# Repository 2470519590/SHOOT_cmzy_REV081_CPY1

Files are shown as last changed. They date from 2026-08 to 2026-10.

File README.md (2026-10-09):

# SHOOT_cmzy_REV081 枪管固件

## 项目职责

固件运行于 STM32F072C8x，负责双路红外 ADC 检测、射击计数与测速、热量和 LED 状态，以及 500 kbps 标准 CAN 通信。检测链路已经完全迁移到 DAC + ADC + DMA；运行时不再使用 VCNL4040、I2C 或旧 `shoot_detect` 检测器。

## ADC 采集与物理命名

- PA4/PA5：DAC 红外发射端，默认码值由 `ir_acquisition.h` 定义。
- PA1/ET1：物理后端，统一命名为 `barrel_rear`。
- PA3/ET2：物理前端，统一命名为 `barrel_front`。
- ADC DMA 原始顺序为 `[ET1, ET2, ...]`，50 μs 一个样本对，约 20 kHz/通道。
- `ir_acquisition` 只负责 DAC、ADC、DMA、定时和物理映射；`ir_detection` 只负责算法和诊断；`main` 负责业务副作用与调度。
- SWD 原始捕获保留 2000 帧结构：500 帧预触发、1500 帧后触发。

## 检测算法

启动和 `0x220` 重校准使用约 1 s 采样窗口，并以稳健中值建立两路基线。运行时先比较样本与阈值，再按约 `1/2048` 慢速更新基线。

```text
front_threshold = front_baseline + 60 ADC
rear_threshold  = rear_baseline + 18 ADC
front/rear 最大脉宽 = 6 ms
rear 最小脉宽 = 0.3 ms
速度范围 = 2~15 m/s
传感器间距 = 50 mm
```

物理顺序为后端先、前端后。前端每个有效脉冲始终产生一个且仅一个射击事件；后端只作为可选测速候选。测速使用峰值时间差：

```text
peak_delta_us = front_peak_us - rear_peak_us
3.333 ms <= peak_delta_us <= 25 ms
speed = 50 mm / peak_delta
```

后端候选使用 8 项队列，前端事件选择时间窗内最近的、尚未消费的后端峰值。没有有效匹配时速度无效，但前端射击计数不受影响。`barrel_mask` 固定为 `0`。

主要 Ozone 变量包括：`barrel_front_adc_raw`、`barrel_rear_adc_raw`、两路 baseline/trigger level、事件数和采样号、峰值 ADC/采样号、`ir_shot_count`、`ir_last_speed_mps`、`ir_last_speed_valid`、`ir_last_peak_delta_us`、`ir_pair_timeout_count`、`ir_unpaired_front_count` 和 `ir_unpaired_rear_count`。

## 应用链路

`main` 从检测层取出事件后执行一次本地计数关联、每发热量 `+10`（上限 200）和顶部 LED 效果，然后将同一个事件交给 CAN 发送队列。CAN 发送失败只保留队列事件重试，不重复执行本地热量和灯效。

- `0x230`：累计次数、速度（`uint16 = round(m/s × 10)`（分辨率 0.1 m/s），无效为 `0xFFFF`）、固定 `barrel_mask=0`、本发后热量。
- `0x232`：累计次数、最近速度（无效为 `0xFFFF`）、固定 `barrel_mask=0`、当前热量。
- `0x220`：主循环启动约 1 s ADC 重校准，校准期间不生成事件。
- `0x221`：前/后端校准前后 baseline，各一个小端 `uint16`。

完整字段和接收约束见 [docs/CAN_PROTOCOL.md](docs/CAN_PROTOCOL.md)。

## 目录

| 路径 | 用途 |
|---|---|
| `Core/Src/ir_acquisition.c` | DAC、ADC、DMA、采样定时和物理通道映射 |
| `Core/Src/ir_detection.c` | 基线、阈值、脉冲、峰值、候选匹配、事件和校准 |
| `Core/Src/main.c` | 初始化、事件消费、热量、LED、CAN 重试和任务调度 |
| `Core/Src/can_protocol.c` | CAN 编码、发送和接收协议 |
| `Core/Src/thermal.c` | 热量累加与冷却 |
| `Core/Src/led_rgb.c` | 顶部灯、队伍色、热量条和故障显示 |
| `Core/Src/reliability.c` | 弱故障及复位记录 |
| `tool/simulate_ir_detection.py` | ADC CSV 逐点回放参考实现 |
| `docs/adc_detection_tuning.md` | ADC 检测参数与诊断说明 |

## 构建与验证

使用现有 VS Code task `STM32: Build`，等价于：

```text
E:\GnuWin32\bin\make.exe -j2 all
```

软件验证包括 Python 数据回放、旧路径静态搜索、`git diff --check`、固件构建以及 ELF 的 SRAM/Flash 使用检查。未执行刷机；实板 Ozone 观察、CAN 总线和机械过管验证仍需在硬件环境完成。

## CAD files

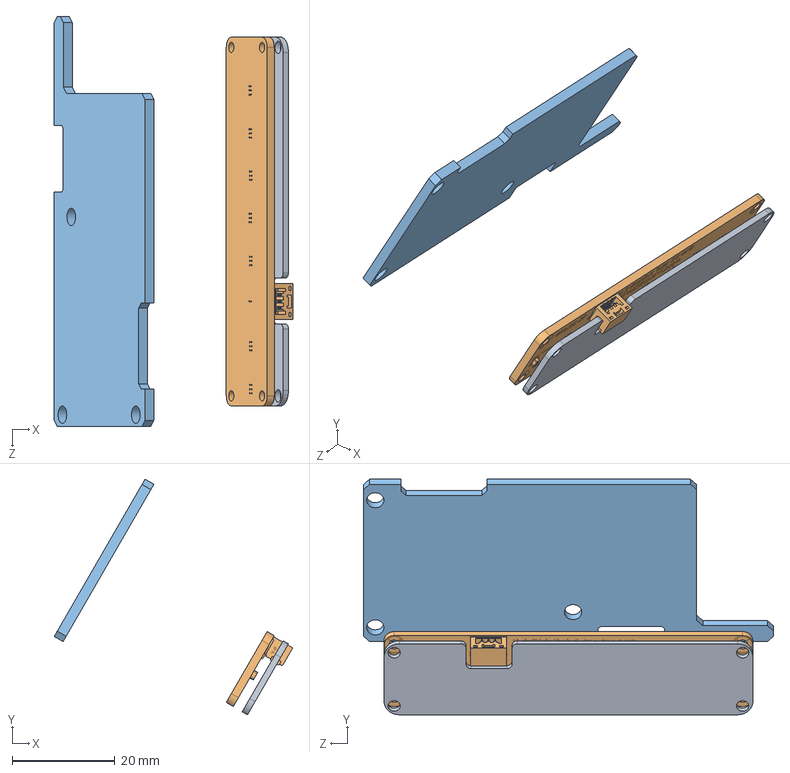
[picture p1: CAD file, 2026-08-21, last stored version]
3Ds/枪管081.SLDASM
46.5 x 46.0 x 80.0 mm
枪管驱动盖
3D_RGB_SHOOT_PCB1_2026-06-19.step
均光板_PCB

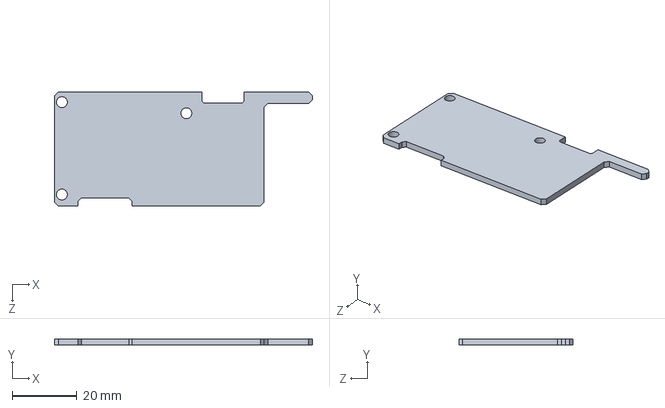
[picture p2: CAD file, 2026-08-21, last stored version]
3Ds/枪管驱动盖.SLDPRT
80.0 x 2.00 x 35.5 mm

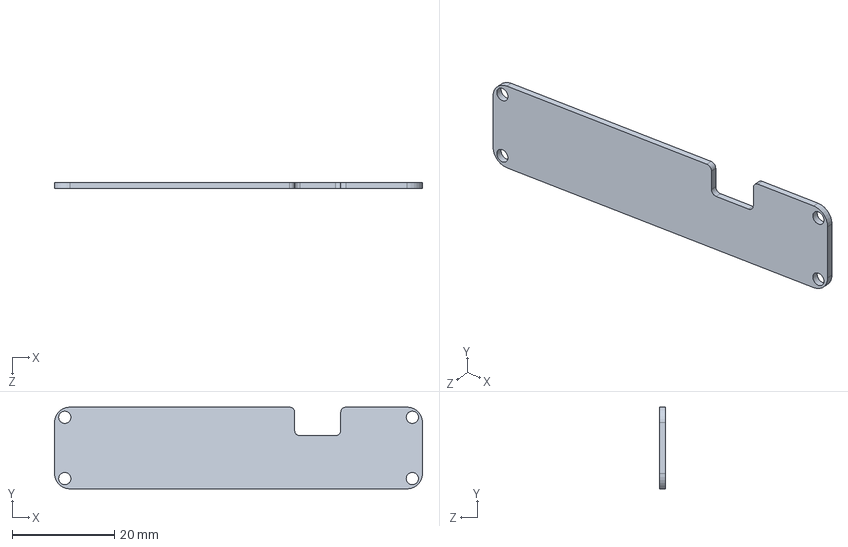
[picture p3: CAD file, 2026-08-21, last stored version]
3Ds/均光板_PCB.SLDPRT
72.0 x 16.0 x 1.20 mm

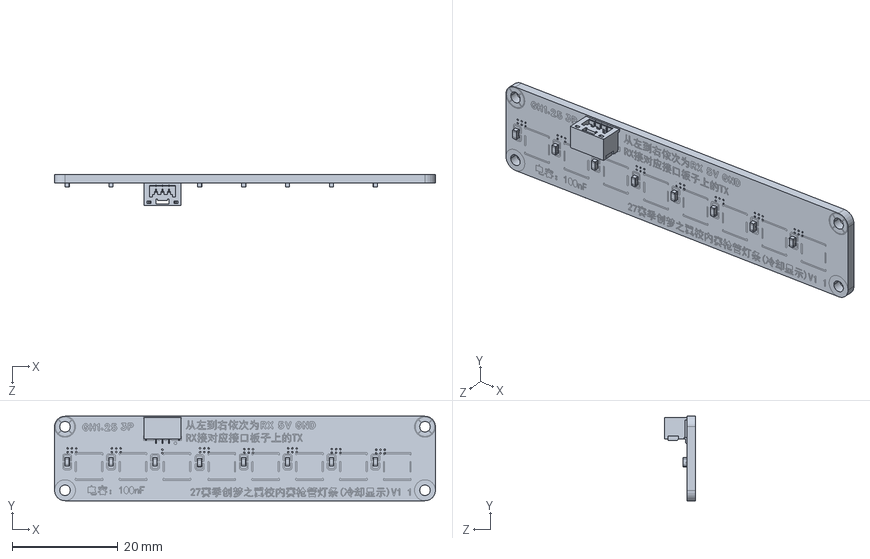
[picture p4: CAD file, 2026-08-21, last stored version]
3Ds/3D_RGB_SHOOT_PCB1_2026-06-19.step.SLDPRT
72.0 x 16.0 x 5.92 mm

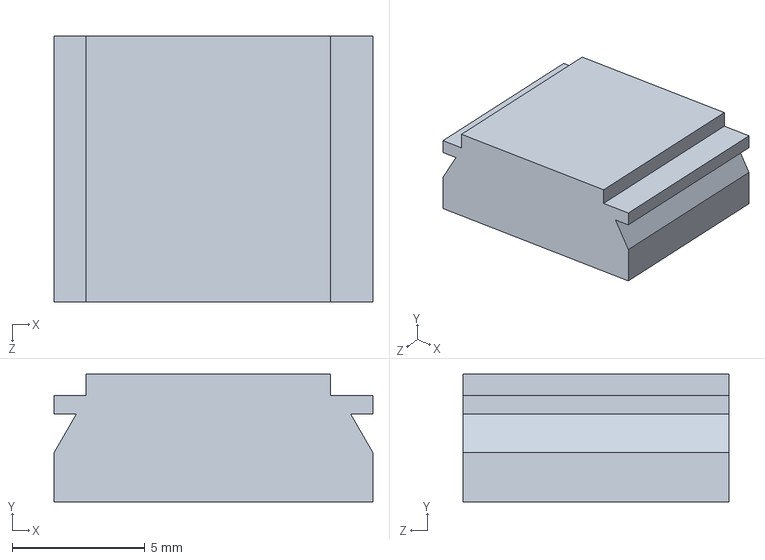
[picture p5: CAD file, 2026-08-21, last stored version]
3Ds/均光板盖.SLDPRT
12.0 x 4.80 x 10.0 mm

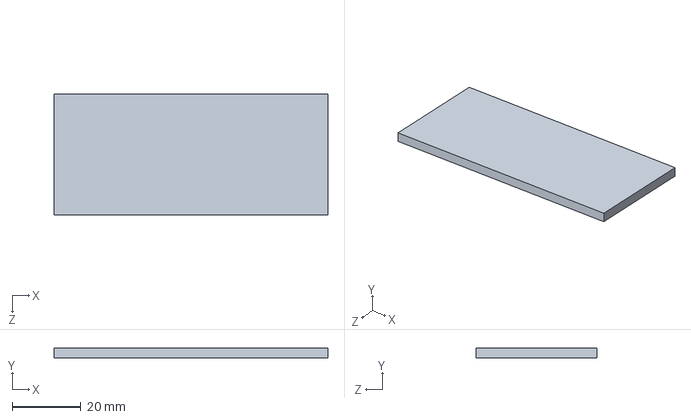
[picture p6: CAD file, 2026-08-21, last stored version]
3Ds/备份 属于 枪管驱动盖.SLDPRT
80.0 x 3.00 x 35.5 mm

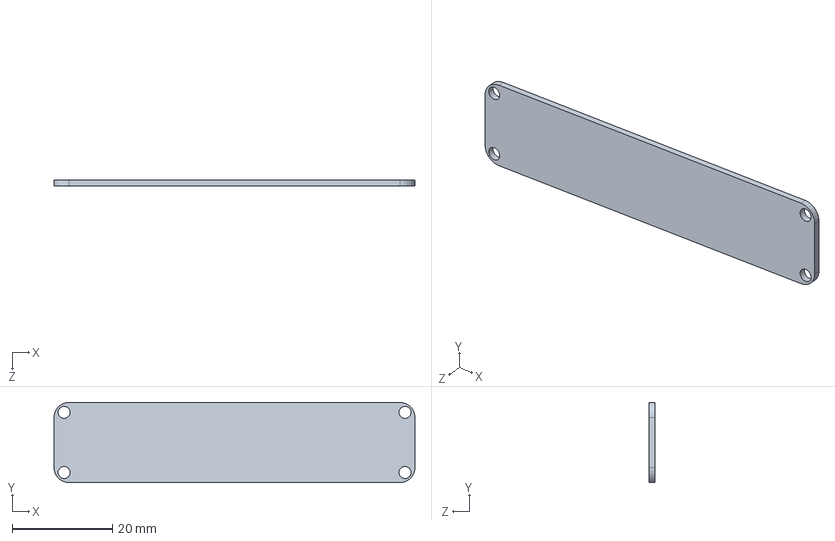
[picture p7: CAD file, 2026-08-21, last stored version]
3Ds/备份 属于 均光板_PCB.SLDPRT
72.0 x 16.0 x 1.20 mm

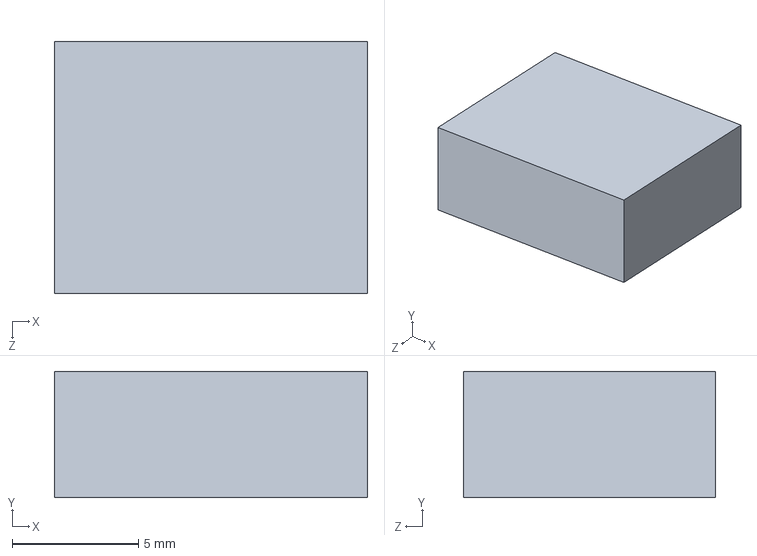
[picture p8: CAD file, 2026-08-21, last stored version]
3Ds/备份 属于 均光板盖.SLDPRT
12.4 x 5.00 x 10.0 mm

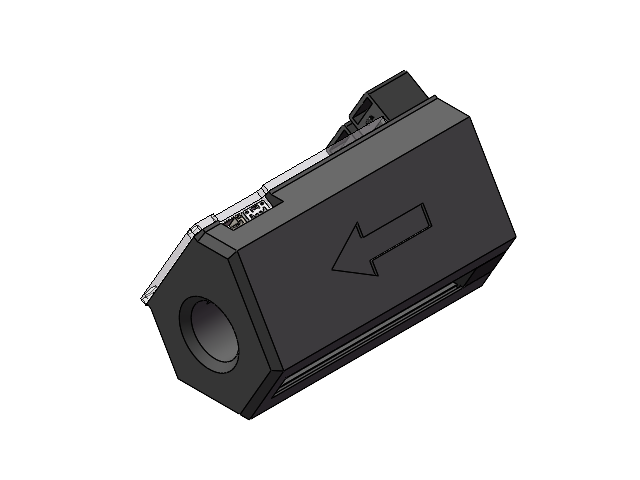
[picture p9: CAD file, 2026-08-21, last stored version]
3Ds/枪管08.SLDASM
枪管08
3D_EVE_0.8.1_2026-06-16.step
枪管驱动盖
均光板盖

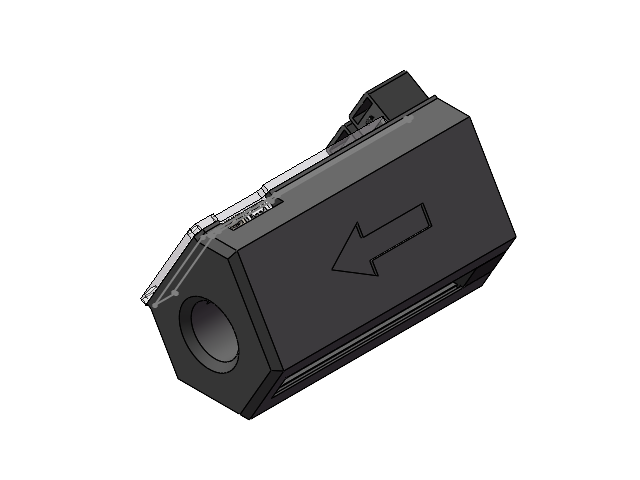
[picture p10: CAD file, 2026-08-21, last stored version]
3Ds/备份 属于 枪管08.SLDASM
枪管08
3D_EVE_0.8.1_2026-06-16.step
枪管驱动盖
均光板盖

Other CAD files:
3Ds/备份 属于 枪管081.SLDASM
3Ds/备份 属于 3D_RGB_SHOOT_PCB1_2026-06-19.step.SLDPRT
3Ds/3D_RGB_SHOOT_PCB1_2026-06-19.step
3Ds/备份 属于 枪管08.SLDPRT
3Ds/备份 属于 枪管081.SLDPRT
3Ds/枪管08.SLDPRT
3Ds/枪管081.SLDPRT

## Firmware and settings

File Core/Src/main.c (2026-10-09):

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
/* Includes ------------------------------------------------------------------*/
#include "main.h"

/* USER CODE BEGIN Includes */
#include "ir_acquisition.h"
#include "ir_detection.h"
#include "can_protocol.h"
#include "led_rgb.h"
#include "ws2812_uart.h"
#include "reliability.h"
#include "thermal.h"
/* USER CODE END Includes */

CAN_HandleTypeDef hcan;

DAC_HandleTypeDef hdac;
ADC_HandleTypeDef hadc;
DMA_HandleTypeDef hdma_adc;

TIM_HandleTypeDef htim3;

TIM_HandleTypeDef htim14;
TIM_HandleTypeDef htim15;
TIM_HandleTypeDef htim16;

UART_HandleTypeDef huart1;
UART_HandleTypeDef huart3;
DMA_HandleTypeDef hdma_usart3_tx;
IWDG_HandleTypeDef hiwdg;

/* USER CODE BEGIN PV */
ShootData_Report_t g_shoot_report;
CAN_ErrorStats_t g_can_stats = {0};

/* 10 Hz status-report tick (set by TIM14 ISR, cleared by main loop) */
volatile bool g_sensor_tick_10hz = false;

/* 10 Hz LED refresh tick (set by TIM15 ISR, cleared by main loop) */
volatile bool g_led_tick_10hz = false;

/* Firmware identity and shot-to-LED trace points.
   This value is deliberately changed with this diagnostic build.  It lets the
   debugger prove which image is executing; it is not derived from the source
   timestamp. */
#if SHOOT_CAN_DIAGNOSTIC_SILENT
#define FW_BUILD_MAGIC  0x26091002UL /* CAN silent diagnostic image */
#elif SHOOT_CAN_DIAGNOSTIC_NO_APP_TX
#define FW_BUILD_MAGIC  0x26091004UL /* RX-only + reset-cause diagnostic */
#else
#define FW_BUILD_MAGIC  0x26083001UL /* normal operational image */
#endif
volatile uint32_t g_dbg_firmware_build_magic = FW_BUILD_MAGIC;
/* A mailbox accept is not yet a physical CAN ACK; it only means bxCAN took
   the 0x230 request.  Keep the two counters separate from sensor counters. */
volatile uint32_t g_dbg_shot_mailbox_accept_count = 0;
volatile uint32_t g_dbg_shot_led_start_count = 0;
volatile uint32_t g_dbg_last_shot_led_event_count = 0;

/* Keep CAN fault evidence as scalar volatile symbols.  Some GDB frontends
 * cannot create a watch for a member of CAN_ErrorStats_t, especially after
 * -Og optimisation.  These are deliberately boring debugger entry points. */
volatile uint32_t g_dbg_can_esr = 0U;
volatile uint32_t g_dbg_can_btr = 0U;
volatile uint8_t  g_dbg_can_lec = 0U;
volatile uint8_t  g_dbg_can_tec = 0U;
volatile uint8_t  g_dbg_can_rec = 0U;
volatile uint8_t  g_dbg_can_bus_off = 0U;

/* Debug LED override — write from debugger:
   g_led_cmd = 1 → 9 LEDs all green  (WS2812_COLOR(255,0,0))
            = 2 → 9 LEDs all red    (WS2812_COLOR(0,255,0))
            = 3 → 9 LEDs all blue   (WS2812_COLOR(0,0,255))
            = 4 → team color (current team)
            = 5 → all off
            = 0 → normal operation (自动)
   Set g_led_cmd_count to limit lit LEDs (0 = all 9). */
volatile uint8_t  g_led_cmd        = 0;
volatile uint8_t  g_led_cmd_count  = 0;
volatile uint8_t  g_heat_debug     = 0;   /* current local heat, 0–200           */
/* ADC detection owns calibration readiness after its startup window. */
static bool g_boot_report_pending = true;
static uint8_t g_pending_strong_fault;
/* USER CODE END PV */



void SystemClock_Config(void);
static void MX_GPIO_Init(void);
static void MX_DMA_Init(void);
static void MX_CAN_Init(void);
static void MX_USART1_UART_Init(void);
static void MX_DAC_Init(void);
static void MX_USART3_UART_Init(void);
static void MX_TIM14_Init(void);
static void MX_TIM15_Init(void);
static void MX_TIM16_Init(void);
static void MX_IWDG_Init(void);
/**
  * @brief  The application entry point.
  * @retval int
  */
int main(void)
{

  /* MCU Configuration--------------------------------------------------------*/

  /* Reset of all peripherals, Initializes the Flash interface and the Systick. */
  HAL_Init();

  /* Read the reset cause and any retained HardFault/CAN Bus-Off note. */
  Reliability_EarlyInit();

  /* Configure the system clock */
  SystemClock_Config();

  /* Initialize all configured peripherals */
  MX_GPIO_Init();
  MX_DMA_Init();
  MX_CAN_Init();
  MX_DAC_Init();
  MX_USART1_UART_Init();
  MX_USART3_UART_Init();
  MX_TIM14_Init();
  MX_TIM15_Init();
  MX_TIM16_Init();
  /* USER CODE BEGIN 2 */

  /* ---- NVIC configuration ---- */
  Thermal_Init(HAL_GetTick());
  HAL_NVIC_DisableIRQ(EXTI4_15_IRQn);
  HAL_NVIC_SetPriority(TIM14_IRQn, 3, 0);      /* TIM14: 10 Hz sensor tick   */
  HAL_NVIC_EnableIRQ(TIM14_IRQn);
  HAL_NVIC_SetPriority(TIM15_IRQn, 3, 0);      /* TIM15: 10 Hz LED tick       */
  HAL_NVIC_EnableIRQ(TIM15_IRQn);
  HAL_NVIC_SetPriority(CEC_CAN_IRQn, 2, 0);    /* CAN: referee comms         */
  HAL_NVIC_EnableIRQ(CEC_CAN_IRQn);

  /* Start TIM16 free-running counter (PSC/ARR set by MX_TIM16_Init) */
  __HAL_TIM_ENABLE(&htim16);

  /* ---- Start fixed-code DAC emitters and timer-triggered raw acquisition ---- */
  IR_Detection_Init();
  IR_Acquisition_RegisterSampleHandler(IR_Detection_OnPhysicalSample);
  if (IR_Acquisition_Init() != HAL_OK) {
      Error_Handler();
  }
  /* The ADC detector owns the application shot path. */
  Reliability_SetWeakFault(REL_WEAK_SHOOT_DETECT, true);

  /* ---- Init board status LED (RGB_TX3) and eight-pixel strip (RGB_TX2) ---- */
  LedStrip_Init();
  LedStrip_SetTeam(TEAM_BLUE);
  LedStrip_StartBootEffect(HAL_GetTick());

  /* ---- Init CAN protocol (slave-only) ---- */
  CANProtocol_Init(&hcan);
  /* Only receive the gun command range (0x220..0x23F), standard data frames.
     Armor-board traffic never reaches this CAN RX ISR. */
  CAN_FilterTypeDef can_filter = {0};
  can_filter.FilterBank = 0;
  can_filter.FilterMode = CAN_FILTERMODE_IDMASK;
  can_filter.FilterScale = CAN_FILTERSCALE_32BIT;
  can_filter.FilterIdHigh = 0x4400; /* 0x220 << 5 */
  can_filter.FilterIdLow = 0x0000;
  can_filter.FilterMaskIdHigh = 0xFC00; /* match 0x220..0x23F */
  can_filter.FilterMaskIdLow = 0x0006;  /* IDE=0, RTR=0 */
  can_filter.FilterFIFOAssignment = CAN_FILTER_FIFO0;
  can_filter.FilterActivation = ENABLE;
  can_filter.SlaveStartFilterBank = 0;
  if (HAL_CAN_ConfigFilter(&hcan, &can_filter) != HAL_OK) {
      Error_Handler();
  }
  /* Start CAN and enable receive interrupt.  The silent diagnostic image
     deliberately remains fully powered and receives 0x220..0x23F, but bxCAN
     neither ACKs nor drives any CAN bit.  It is only for isolating a
     gun-side CAN fault; production builds always use normal mode. */
  if (HAL_CAN_Start(&hcan) != HAL_OK) {
      Error_Handler();
  }
  if (HAL_CAN_ActivateNotification(&hcan,
        CAN_IT_RX_FIFO0_MSG_PENDING) != HAL_OK) {
      Error_Handler();
  }
  g_can_stats.state = (uint8_t)HAL_CAN_GetState(&hcan);

  MX_IWDG_Init();

  /* Report a prior strong reset before announcing this successful startup. */
  g_pending_strong_fault = Reliability_GetPendingStrongMask();
  /* Keep the debugger-visible image identity linked into the final ELF. */
  if (g_dbg_firmware_build_magic != FW_BUILD_MAGIC) {
      Error_Handler();
  }
  /* USER CODE END 2 */

  /* Infinite loop */
  /* USER CODE BEGIN WHILE */
  while (1)
  {
    /* USER CODE END WHILE */

    /* USER CODE BEGIN 3 */
    if (CANProtocol_TakeCalibrationRequest()) {
        (void)IR_Detection_RequestCalibration();
    }

    IR_Acquisition_PublishLatest();
    IR_Acquisition_ServiceRawCapture();
    if (g_pending_strong_fault != 0U &&
        CANProtocol_SendStrongFault(g_pending_strong_fault) == HAL_OK) {
        g_pending_strong_fault = 0U;
    }
    if (g_boot_report_pending && g_pending_strong_fault == 0U &&
        IR_Detection_IsCalibrationReady() &&
        CANProtocol_SendBoot() == HAL_OK) {
        g_boot_report_pending = false;
    }

    static uint16_t old_front, new_front, old_rear, new_rear;
    static bool calibration_ack_pending;
    if (!calibration_ack_pending &&
        IR_Detection_TakeCalibrationResult(&old_front, &new_front,
                                           &old_rear, &new_rear)) {
        calibration_ack_pending = true;
    }
    if (calibration_ack_pending &&
        CANProtocol_SendCalibrationAck(old_front, new_front,
                                       old_rear, new_rear) == HAL_OK) {
        calibration_ack_pending = false;
    }

    uint32_t now_tick = HAL_GetTick();
    Thermal_Update(now_tick);
    g_heat_debug = Thermal_GetHeat();
    LedStrip_SetOverheatAlert(
        Thermal_IsOverheatIndicatorActive(now_tick));

    /* Drain acquisition events regardless of CAN availability. */
    static ShootEvent_t can_shots[IR_SHOT_EVENT_CAPACITY];
    static uint8_t can_shot_head, can_shot_count;
    static uint32_t can_shot_dropped;
    static uint32_t locally_accounted_shots;
    ShootEvent_t shot_event;
    while (IR_Detection_PeekShotEvent(&shot_event)) {
        IR_Detection_DropShotEvent();
        /* Count gaps represent detection queue loss, not lost physical shots. */
        while ((int32_t)(shot_event.shot_count - locally_accounted_shots) > 0) {
            locally_accounted_shots++;
            g_heat_debug = Thermal_AddShot(now_tick);
            g_dbg_shot_led_start_count++;
            g_dbg_last_shot_led_event_count = locally_accounted_shots;
            LedStrip_StartShotEffect(now_tick);
        }
        shot_event.heat_level = g_heat_debug;
        if (can_shot_count < IR_SHOT_EVENT_CAPACITY) {
            uint8_t tail = (uint8_t)((can_shot_head + can_shot_count) % IR_SHOT_EVENT_CAPACITY);
            can_shots[tail] = shot_event;
            can_shot_count++;
        } else {
            can_shot_dropped++;
        }
    }
    /* Preserve local behavior even when the detection event queue overflowed. */
    uint32_t shot_primask = __get_PRIMASK();
    __disable_irq();
    uint32_t detected_shots = IR_Detection_PeekShotEvent(&shot_event)
        ? locally_accounted_shots : ir_shot_count;
    __set_PRIMASK(shot_primask);
    while ((int32_t)(detected_shots - locally_accounted_shots) > 0) {
        locally_accounted_shots++;
        g_heat_debug = Thermal_AddShot(now_tick);
        g_dbg_shot_led_start_count++;
        g_dbg_last_shot_led_event_count = locally_accounted_shots;
        LedStrip_StartShotEffect(now_tick);
    }
    if (can_shot_count != 0U &&
        CANProtocol_SendShotEvent(&can_shots[can_shot_head]) == HAL_OK) {
        g_dbg_shot_mailbox_accept_count++;
        can_shot_head = (uint8_t)((can_shot_head + 1U) % IR_SHOT_EVENT_CAPACITY);
        can_shot_count--;
    }

    /* Queries are queued by CAN RX ISR and replied from the main loop. */
    CANProtocol_Task();

    /* CAN 0x200 remains reserved for debug heartbeat but is idle in this build. */

    /* Keep raw CAN controller diagnostics visible in the debugger. */
    uint32_t can_esr = CAN->ESR;
    g_dbg_can_esr = can_esr;
    g_dbg_can_btr = CAN->BTR;
    g_dbg_can_lec = (uint8_t)((can_esr & CAN_ESR_LEC) >> CAN_ESR_LEC_Pos);
    g_dbg_can_tec = (uint8_t)((can_esr & CAN_ESR_TEC) >> CAN_ESR_TEC_Pos);
    g_dbg_can_rec = (uint8_t)((can_esr & CAN_ESR_REC) >> CAN_ESR_REC_Pos);
    g_dbg_can_bus_off = (uint8_t)((can_esr & CAN_ESR_BOFF) != 0U);
    g_can_stats.last_error_lec = (uint8_t)((can_esr & CAN_ESR_LEC) >> CAN_ESR_LEC_Pos);
    g_can_stats.tx_error_counter = (uint8_t)((can_esr & CAN_ESR_TEC) >> CAN_ESR_TEC_Pos);
    g_can_stats.rx_error_counter = (uint8_t)((can_esr & CAN_ESR_REC) >> CAN_ESR_REC_Pos);
    g_can_stats.bus_off = (uint8_t)((can_esr & CAN_ESR_BOFF) != 0U);
    g_can_stats.state = (uint8_t)HAL_CAN_GetState(&hcan);

    /* 10 Hz tasks: status report refresh */
    if (g_sensor_tick_10hz) {
        g_sensor_tick_10hz = false;

        static uint32_t last_adc_activity;
        uint32_t adc_activity = adc_activity_count;
        bool adc_alive = ir_acquisition_ready &&
                         (adc_activity != last_adc_activity);
        last_adc_activity = adc_activity;
        Reliability_ObserveSensors(adc_alive, adc_alive);
        /* A valid startup/recalibration window establishes ADC thresholds. */
        if (!IR_Detection_IsCalibrationReady()) {
            Reliability_SetWeakFault(REL_WEAK_SHOOT_DETECT, true);
        } else {
            Reliability_SetWeakFault(REL_WEAK_SHOOT_DETECT, false);
        }
        Reliability_ObserveEventQueueDropped(
            IR_Detection_GetDroppedEventCount() + can_shot_dropped);

        g_shoot_report.shot_count      = ir_shot_count;
        g_shoot_report.front_int_count = barrel_front_event_count;
        g_shoot_report.rear_int_count  = barrel_rear_event_count;
        g_shoot_report.last_speed_mps  = ir_last_speed_valid ? ir_last_speed_mps : 0.0f;
        g_shoot_report.barrel_mask     = 0U;
        g_shoot_report.heat_level      = g_heat_debug;
        g_shoot_report.front_prox      = IR_GetBarrelPhysicalFrontAdc();
        g_shoot_report.rear_prox       = IR_GetBarrelPhysicalRearAdc();
        CANProtocol_UpdateData(&g_shoot_report);
    }

    /* Feed the display model before any animation renders. Team commands
       configure the automatic strip; heat includes shots accounted above.
       The CAN ISR never calls the LED transport or renderer. */
    LedStrip_SetTeam(CANProtocol_GetLedCommand()->team == 0U
                     ? TEAM_RED : TEAM_BLUE);
    LedStrip_SetRefereeData(g_heat_debug);
    bool boot_effect_active = LedStrip_ProcessBootEffect(now_tick);
    bool shot_effect_active = false;
    if (!boot_effect_active &&
        (Reliability_GetWeakMask() & (uint8_t)~REL_WEAK_SHOOT_DETECT) == 0U &&
        g_led_cmd == 0 && CANProtocol_GetLedCommand()->source != LED_SRC_DEBUG) {
        shot_effect_active = LedStrip_ProcessShotEffect(now_tick);
    }

    if (g_led_tick_10hz) {
        g_led_tick_10hz = false;

        /* Priority 1: one-shot power-on confirmation of the lower eight LEDs. */
        if (boot_effect_active) {
            /* LedStrip_ProcessBootEffect() has already sent this frame. */
        }
        /* Priority 2: any active fault overrides ordinary LED control. */
        else if ((Reliability_GetWeakMask() & (uint8_t)~REL_WEAK_SHOOT_DETECT) != 0U) {
            LedStrip_ShowFaultAlert(HAL_GetTick());
        }
        /* Priority 3: debugger override (g_led_cmd = 1~5) */
        else if (g_led_cmd != 0) {
            LedStrip_TestPattern(g_led_cmd, g_led_cmd_count);
        }
        /* Priority 4: CAN LED command */
        else if (CANProtocol_GetLedCommand()->source == LED_SRC_DEBUG) {
            LedStrip_ApplyCommand(CANProtocol_GetLedCommand());
        }
        /* Priority 5: valid-shot animation; it is updated every main-loop pass. */
        else if (shot_effect_active) {
            /* LedStrip_ProcessShotEffect() has already sent this frame. */
        }
        /* Priority 6: auto — follow shoot detection */
        else {
            LedStrip_SetRefereeData(g_heat_debug);
            LedStrip_Update();
        }
    }

    /* Weak fault notification is best-effort and never blocks the main loop. */
    static uint8_t last_weak_mask = 0U;
    static bool weak_mask_initialized = false;
    static uint32_t weak_fault_tx_tick = 0U;
    uint8_t weak_mask = Reliability_GetWeakMask();
    if ((!weak_mask_initialized && weak_mask != 0U) ||
        (weak_mask_initialized && weak_mask != last_weak_mask &&
         (now_tick - weak_fault_tx_tick) >= 100U) ||
        (weak_mask != 0U &&
         (now_tick - weak_fault_tx_tick) >= 100U)) {
        HAL_StatusTypeDef weak_tx_status =
            CANProtocol_SendWeakFault(weak_mask);
        weak_fault_tx_tick = now_tick;
        if (weak_tx_status == HAL_OK) {
            last_weak_mask = weak_mask;
        }
    }
    weak_mask_initialized = true;

    /* Main-loop-only watchdog feed: do not feed it from any ISR. */
    (void)HAL_IWDG_Refresh(&hiwdg);
    HAL_Delay(1);
  }
  /* USER CODE END 3 */
}

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
/* USER CODE BEGIN 4 */

/**
  * @brief  TIM14 period elapsed callback — fires at 10 Hz.
  *         Sets a flag for the main loop to read sensors.
  */
void HAL_TIM_PeriodElapsedCallback(TIM_HandleTypeDef *htim)
{
    if (htim->Instance == TIM14) {
        g_sensor_tick_10hz = true;
    }
    if (htim->Instance == TIM15) {
        g_led_tick_10hz = true;
    }
}

/* USER CODE END 4 */
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


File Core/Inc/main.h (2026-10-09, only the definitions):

#define IND_1_Pin GPIO_PIN_5
#define IND_1_GPIO_Port GPIOA
#define RGB_UART3_TX_Pin GPIO_PIN_10
#define RGB_UART3_TX_GPIO_Port GPIOB
#define IR_DAC1_Pin GPIO_PIN_4
#define IR_DAC1_GPIO_Port GPIOA
#define IR_DAC2_Pin GPIO_PIN_5
#define IR_DAC2_GPIO_Port GPIOA
#define IR_ET1_Pin GPIO_PIN_1
#define IR_ET1_GPIO_Port GPIOA
#define IR_ET2_Pin GPIO_PIN_3
#define IR_ET2_GPIO_Port GPIOA
#define CAN_RX_Pin GPIO_PIN_8
#define CAN_RX_GPIO_Port GPIOB
#define CAN_TX_Pin GPIO_PIN_9
#define CAN_TX_GPIO_Port GPIOB
#define RGB_UART1_TX_Pin GPIO_PIN_6
#define RGB_UART1_TX_GPIO_Port GPIOB
#define RGB_UART1_RX_Pin GPIO_PIN_7
#define RGB_UART1_RX_GPIO_Port GPIOB

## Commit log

2026-08-21 编译命令
2026-09-01 整理文档，恢复50ms清除
    [sensor_capture.csv]
2026-09-06 删除3Ds文件夹
    [3D_RGB_SHOOT_PCB1_2026-06-19.step, 3D_RGB_SHOOT_PCB1_2026-06-19.step.SLDPRT, 均光板_PCB.SLDPRT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]
2026-09-06 删除uart2任务
2026-09-17 暂存，旧固件
2026-10-02 暂存10/2
2026-10-09 新版传感器
    [simulation_events_front60.csv, simulation_front60_all.csv, simulation_front60_speed15.csv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]

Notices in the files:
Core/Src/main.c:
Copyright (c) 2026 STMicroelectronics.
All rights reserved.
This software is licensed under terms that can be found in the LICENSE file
